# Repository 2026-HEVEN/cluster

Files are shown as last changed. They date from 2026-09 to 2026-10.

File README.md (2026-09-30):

# HEVEN Cluster 펌웨어

**2026 영광 대회 · 계기 클러스터(Instrument Cluster)** — ESP32가 CAN/BLE로 차량 상태(속도·전압·SOC·온도·에러)를 **받아서** LCD에 표현하고, 계기판 버튼 입력을 VCU로 보냅니다. PCB V3에서는 VESS PWM도 Cluster가 직접 출력합니다. VCU와 달리 **안전 임계가 약한 표시 전용 보드**입니다.

> 🤖 **AI 에이전트/팀원은 [`AGENTS.md`](AGENTS.md)를 먼저 읽으세요** — 무엇을 고쳐도 되고 무엇을 건드리면 안 되는지 규칙이 있습니다.

---

## 한눈에

- **스택**: PlatformIO + Arduino-ESP32, TWAI(CAN), ILI9341 LCD. 화면은 **패널 독립적 1bpp 프레임버퍼**(위젯이 그림) + `display_blit`(ILI9341로 blit)
- **구조**: 잠긴 코어(CAN·프레임버퍼·blit) + 팀원이 채우는 순수 모듈(`src/modules/`). VCU와 **동일한 2층 설계**지만 안전 FSM·50ms 라이프 태스크가 없고 CAN은 **수신(RX) 위주**입니다.
- **상태**: ESP32 빌드 성공, 호스트 native 테스트 111개 통과

## 사용자 문서

- [계기판 기능 및 한계](docs/ui_report/REPORT.md)
- [계기판 사용설명서](docs/ui_report/USER_MANUAL.md)
- [추가 CAN 정보 및 실차 확인 사항](docs/ui_report/CAN_DATA_REQUIRED.md)

## 빠른 시작

```bash
# 1. 이 레포를 깨끗한 위치에 클론
git clone https://github.com/2026-HEVEN/cluster.git
cd cluster

# 2. PlatformIO 설치 (한 번만) — VS Code면 PlatformIO IDE 확장 설치로 대체 가능
uv tool install platformio      # 또는: pipx install platformio

# 3. 노트북에서 테스트 (하드웨어 불필요)
pio test -e native

# 4. 보드에 빌드 & 업로드 (ESP32 연결 상태에서)
pio run -e esp32dev -t upload
```

> 🧪 **테스트가 처음이거나 Windows 사용자라면** → 노션 [펌웨어 테스트 실행 방법](https://www.notion.so/390913e532e68199a9b5e340b73e9e71) 참고. AI에 복붙할 프롬프트 + "이렇게 나오면 성공" 출력 예시 + Windows(WSL2/MinGW) 셋업까지 있습니다. (보드 업로드는 Windows도 그냥 되고, `native` 단위테스트만 host 컴파일러가 필요해요.)

> ℹ️ 모터컨트롤러 값은 MCU→VCU 피드백 프레임을 Cluster가 같은 CAN 버스에서 수신합니다. BMS SOC는 `LWS-1608` BLE BMS에 Cluster ESP32가 직접 연결해 표시용 telemetry로만 읽습니다.
> ℹ️ 계기판 속도 표시는 VCU가 내부 `vehicle_speed_compute()`로 산출한 단일 차량속도 프레임 `0x1803C0D0`을 사용합니다. 이 값은 전륜 기준 보정 로직을 거친 `km/h x 10` 값이며, Cluster는 다시 네 바퀴 평균을 내지 않습니다.
> ℹ️ GPS Lap Start는 현재 GNSS fix 위치를 출발점으로 저장합니다. 이후 VCU 단일 차량속도 `0.5 km/h` 초과가 `150ms` 이상 지속되면 랩타이머를 시작하고, 다시 출발점 반경 `2.0m` 안으로 들어오면 랩을 갱신합니다.

## 현재 하드웨어 핀맵 (PCB V3)

| 구분 | 기능 | ESP32 GPIO | 연결/동작 |
|---|---|---|---|
| CAN | TXD | GPIO13 | CAN 트랜시버 TXD |
| CAN | RXD | GPIO14 | CAN 트랜시버 RXD |
| LCD ILI9341 | CS / RST / DC | GPIO23 / 22 / 21 | LCD 제어 |
| LCD / Touch SPI | MOSI / SCK / MISO | GPIO17 / 18 / 35 | 공용 SPI |
| LCD Touch XPT2046 | T_CS | GPIO16 | Touch chip select |
| GPS ZED-F9P | RX / TX / PPS | GPIO25 / 26 / 27 | 115200 baud NMEA/UBX, RTCM3 및 PPS |
| VESS | PWM | GPIO4 | 반전 MOSFET 구동, 50Hz 고정. 외부 RX-TH에는 1~2ms High 펄스 출력 |
| HMI | TV | GPIO32 | 토글 스위치, PCB 외부 10k 풀업, ON=LOW |
| HMI | Paddock | GPIO33 | 토글 스위치, PCB 외부 10k 풀업, ON=LOW |
| HMI | HOME | GPIO19 | 순간 푸시 버튼, PCB 외부 10k 풀업, ON=LOW |
| HMI | GPS Lap | GPIO5 | 순간 푸시 버튼, PCB 외부 10k 풀업, ON=LOW |
| HMI | Regen bit0 / bit1 | GPIO36 / 39 | 로터리, ON=LOW, 두 핀 모두 외부 풀업 필요 |
| Sense | START_IN | GPIO34 | 시동 전원 감지 ADC. 버튼 출력 핀이 아님 |

GPS TX2는 PCB V3에서 Cluster ESP32 `GPIO25` RX에 연결한다.

Cluster는 부팅 시 ZED-F9P UART1/UART2가 460800 baud로 설정되어 있더라도 UBX 설정으로 115200 baud로 낮춘 뒤 통신한다. NMEA가 끊기면 115200 baud 복구를 다시 시도하므로, 같은 GPS TX에 연결된 외부 로거도 115200 baud로 유지할 수 있다.

RTK 사용 시 Cluster ESP32가 Wi-Fi로 NTRIP caster에 접속하고, 수신한 RTCM3 바이트를 가공 없이 `GPIO26` UART TX로 ZED-F9P RX2에 전달한다. 실제 Wi-Fi/NTRIP 계정정보는 `include/ntrip_secrets.h`에 넣고 Git에는 올리지 않는다. `include/ntrip_secrets.example.h`를 복사해서 사용한다.

Cluster는 ZED-F9P RMC의 Speed Over Ground를 km/h로 변환해 새 RMC마다 Extended CAN `0x18F9FFC0`으로 송신한다. 속도는 0.01 km/h/bit이며 같은 프레임에 RMC fresh, GPS fix, RTK FLOAT/FIXED, speed valid, GGA quality와 RMC age를 포함한다. 상세 byte layout은 `docs/CAN_PROTOCOL.md`를 따른다.

회생제동 입력은 GPIO36/39 두 비트 로터리다. 0단은 OFF, 1~3단은 모두 같은 ON 요청으로 인코딩한다. 실제 회생 가능 여부와 전류 제한은 VCU가 최종 판단한다.

GPIO15는 현재 펌웨어에서 사용하지 않는다. GPIO15는 strapping pin이므로 외부 회로가 부팅 순간 강하게 잡아당기지 않게 주의한다.

GPIO34는 PCB V3의 START_IN 전원 감지 ADC다. 5ms마다 분압된 핀 전압을 읽고, 1.5V 이상에서 ON, 1.0V 이하에서 OFF로 판정하며 20ms 디바운스를 적용한다. 이 값은 Car Check의 VCU/SENSOR 상세 화면에 표시할 뿐 차량 제어에는 사용하지 않는다. 기어는 VCU에서 읽는다.
## 어디서 작업하나

| 폴더 | 내용 | 편집? |
|---|---|---|
| `src/modules/` | 순수 계산 함수 `xxx_compute()` | ✅ **여기서만** |
| `test/` | 노트북 단위 테스트 | ✅ |
| `src/core/`, `src/logic/`, `include/` | CAN·framebuffer·display_blit·스케줄러·타입 | 🔒 잠김 |
| `platformio.ini`, `src/main.cpp` | 빌드 설정·진입점 | 🔒 잠김 |

새 모듈을 추가하거나 기존 `compute()`를 채우는 법 → [`docs/ADDING_A_MODULE.md`](docs/ADDING_A_MODULE.md)

## 모듈 목록 (FILL-IN)

- `hmi_input` — config 스위치(패독·TC·회생·디버그) → `ClusterCommand` (CAN으로 VCU에 전송)
- `widgets/` — 계기판 화면 위젯 (speed·battery·warnings·gear ...). 1bpp 프레임버퍼에 그림.
  새 위젯 추가법: `docs/ADDING_A_WIDGET.md`

> 표시는 패널 독립적 **1bpp 프레임버퍼**로. 실제 패널 blit(`display_blit`)은 하드웨어 확정 후 구현.

## 문서

| 문서 | 내용 |
|---|---|
| [`AGENTS.md`](AGENTS.md) / `CLAUDE.md` | 작업 규칙 (에이전트·팀원 필독) |
| [`docs/ADDING_A_MODULE.md`](docs/ADDING_A_MODULE.md) | 모듈 추가/작성 절차 |
| [`docs/CAN_PROTOCOL.md`](docs/CAN_PROTOCOL.md) | CAN 메시지 명세 (VCU/Cluster 공유 단일 출처) |

> 전체 설계 원리(compute/update 분리, state 격리, 테스트 등)는 **VCU 레포의 [`ARCHITECTURE.md`](https://github.com/2026-HEVEN/vcu/blob/main/docs/ARCHITECTURE.md)** 와 동일합니다.

## 아직 미구현 (의도된 TODO)

- **VCU 표시 상태 프레임 구현** — VCU가 `0x1801C0D0`으로 확정 기어/HV/브레이크 상태를 보내면 Cluster가 그 값을 우선 표시합니다.
- **BMS BLE 실차 검증** — `LWS-1608` BLE 이름, `FFE0/FFE1/FFE2` 특성, SOC/current 부호를 실제 배터리팩에서 확인해야 합니다.

## 버전 기록 (Changelog)

> 각 버전은 git 태그로도 관리됩니다 → [GitHub Releases](https://github.com/2026-HEVEN/cluster/releases)
> **새 버전 올릴 때:** 아래에 항목 추가 → `git tag vX.Y` → `git push origin vX.Y`.

### v1.1.1 (2026-07-06) — 위젯 레이아웃 렌더 테스트
- `test/test_render_layout`: `app_wiring.cpp`의 위젯 배치를 그대로 재현해 24bit BMP로 덤프하는 시각화 테스트 추가. `pio test -e native -f test_render_layout` 로 실행 → `render_layout.bmp` 생성(Windows 사진 앱/그림판 등 추가 도구 없이 바로 열림), 위젯별 할당 공간을 박스로 표시
- `.gitignore`에 `*.bmp` 추가

### v1.1 (2026-06-29) — 디스플레이 프레임버퍼 재설계
- 패널 독립적 **1bpp 프레임버퍼**(320×160) + 위젯 모듈(speed · battery · warnings · gear) 도입 — 렌더링을 모듈로 넘겨 자유도↑, host 테스트 가능(ASCII 시각화)
- `hmi_input` → **`ClusterCommand`**(paddock · TC · regen · debug) 의미 커맨드 패턴, **패독 모드** 추가
- **제거**: `vess`, `indicators`, `display_render`(U8g2), `io_expander`(MCP23017)
- `display_blit` stub(패널 확정 후 구현), CAN 커맨드 레이아웃(`CAN_PROTOCOL.md` §5.7) 갱신

### v1.0 (2026-06-29) — 초기 Cluster 펌웨어 베이스
- 잠긴 코어(CAN RX · MCP23017 · U8g2 OLED) + 순수 모듈(display · indicators · vess · hmi_input)
- PlatformIO native 테스트, AGENTS/ADDING_A_MODULE/CAN_PROTOCOL 문서

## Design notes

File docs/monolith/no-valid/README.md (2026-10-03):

# Configurations without standalone validity decoders

- RaceMonitor: 317 channels, SOC included.
- Full: 430 channels, SOC included.

Standalone channel names containing the word `Valid` are removed. Existing
value decoders, including their validity filters, remain unchanged to avoid
displaying invalid sentinel temperatures or LV voltages as physical values.
BLE connection status and other non-validity diagnostics remain available.
Removing a decoder does not remove any CAN frames or reduce bus traffic.

Lap history now keeps the active lap at 5 Hz, the nine latest completed laps
at 1 Hz each, and older completed laps at 0.1 Hz each. These are target rates,
not guaranteed delivery during bus faults or saturation. Old lap values may
show missing in Control Hub if its display timeout is shorter than ten seconds.
The CAN IDs and byte layout are unchanged; the JSON needs no rate setting.

Generation: `tools/remove_monolith_valid.py`. Originals are preserved and all
settings except the explicitly removed channels are checked for equality.

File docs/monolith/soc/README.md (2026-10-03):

# BMS SOC decoder configurations

These copies preserve the supplied RaceMonitor and Full configurations and add
or normalize these channels:

| Name | Extended CAN ID | Range | Type | Multiplier | Unit |
| --- | --- | --- | --- | --- | --- |
| BMS SOC | 0x18F3FFC0 | Byte 1 | unsigned byte | 1 | % |
| BMS Data Valid | 0x18F3FFC0 | Bit 0 | unsigned bit | 1 | State |
| BMS BLE Connected | 0x18F3FFC0 | Bit 1 | unsigned bit | 1 | State |

Offsets are zero. SOC uses little endian and no payload filter, so every BMS
status frame updates its display. Treat SOC as usable only while Data Valid is
1; the decoder does not itself hide stale or disconnected values. BLE Connected
alone is not a freshness guarantee.

Cluster already schedules `bms_can_tx_update` every 100 ms (10 Hz), with both
status and detail sent by `send_bms_status`. This change does not modify that
schedule or the BLE polling rate. Repeated telemetry is not a new BMS measurement.
Successful delivery still depends on CAN health, BMS freshness, and Monolith's
own receive/render behavior. JSON import and on-device rendering need bench
verification; this configuration cannot guarantee an absence of missing values.

The RaceMonitor copy has 319 channels; Full has 436. Full already contained
BMS SOC, so it is not duplicated. Other decoders, units, and settings are retained.

Generation and validation: `tools/add_monolith_soc.py`. Validation covers
unrelated-setting preservation, SOC values 0/1/78/100, validity flag combinations,
idempotence, and a JSON round trip.

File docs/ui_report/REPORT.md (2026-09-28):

# HEVEN Cluster 계기판 기능 및 한계

작업 기준일: 2026-09-28. 대상: PCB V3 Cluster ESP32 / 320×240 ILI9341 LCD.

이번 작업은 노트북 없이 차량 상태를 확인하도록 Car Check를 구성하고, 연결 이력과 최근 60초 그래프를 추가한 펌웨어 변경이다. 그래프를 열 수 있는 항목에는 `*`를 표시했다. 본 문서의 이미지는 **실제 펌웨어 화면 그리기 코드에 예시 데이터를 넣어 생성한 화면 미리보기**이며, 실차 측정 사진이나 실차 검증 결과는 아니다.

운전자 조작 순서는 [Cluster 계기판 사용설명서](USER_MANUAL.md)에 별도로 정리했다.

## 1. 무엇이 바뀌었나

| 항목 | 이전 로컬 구현 | 이번 변경 |
| --- | --- | --- |
| 기본 화면 | WSS 속도, 기어, HV SOC, HV/LV 전압, 랩 정보와 하단 Car Check 진입 칸 | WSS 속도 확대. 기어·HV SOC·HV/LV 전압을 오른쪽 정렬하고 스로틀·전력 막대와 랩 정보를 남는 공간에 재배치 |
| 브레이크 | 압력 데이터가 없어 빈 `BRK --` 막대 표시 | 압력 막대 삭제. VCU의 유효한 Brake Active가 ON일 때만 기어 왼쪽에 `BRK` 표시 |
| 전력 표시 | POWER/CHARGE를 같은 방향의 막대로 표시 | 중앙 0 기준 양방향 막대. CHARGE는 왼쪽, POWER는 오른쪽으로 채워 방향을 즉시 구분 |
| GPS LAP 정지/재개 | Warning 상태에 따라 버튼 동작이 달라져 랩 시작이 제한됨 | Warning 여부와 무관하게 단일 클릭으로 START·STOP·RESUME. 기존 기준점·결승선·랩 기록을 유지하고 정지 시간은 랩타임에서 제외 |
| Car Check | 모터·전원·VCU·GPS 구분 | 최신 VCU 센서와 제어 적용 상태, 차단 이유를 세부 화면에 연결 |
| 그래프 접근 | 홈 화면 WSS 숫자 | 속도 숫자는 WSS 그래프, 전력 막대는 POWER 그래프로 연결. 나머지 홈 영역은 Warning 또는 Car Check로 연결하고 세부 화면의 `*` 항목도 그래프 제공 |
| 저장량 | WSS 최대 20 Hz·10분, 가용 heap에 따라 최대 96 KB | 선택한 12개 수치 2 Hz·최근 60초, 고정 크기 RAM |
| 좌우 비교 | 개별 수치 확인 | 버스 전류·상 전류·버스 전압을 같은 그래프에 표시. L 점선 / R 실선 |
| 통신 진단 | 현재 LIVE/WAIT 확인 | 연속 연결 시간, 단절 횟수, 모터 고장 발생/해제 이력 |
| 화면 갱신 설정 | 약 15 Hz | 50 ms / 20 Hz 목표 |
| LV SOC | 공급 데이터 없음 | 막대와 %를 만들지 않고 LV 전압만 표시 |
| 상세 화면 행 | 화면별 구분 방식이 달랐음 | 모터·전원·VCU·센서·GPS 화면의 데이터 행 구분선을 제거해 통일 |
| PCB 핀맵 | 기존 PCB GPIO 배치 | PCB V3의 LCD·Touch·CAN·GNSS·스위치 핀으로 변경하고 외부 10 kΩ 풀업 기준 입력으로 통일 |
| START 입력 | 표시 없음 | GPIO34 ADC로 분압된 START_IN을 감시하고 VCU/SENSOR 화면에 ON/OFF와 ADC 전압 표시 |
| VESS 출력 | 비반전 GPIO 출력 전제 | GPIO4 단일 반전 MOSFET 회로에 맞춰 PWM duty를 보상하고 외부 출력 2 ms HIGH pulse 유지 |
| 구동계 이상 감지 | 컨트롤러 fault bit와 통신 단절만 경고 | 반복 RPM 결손과 좌우 RPM 발산을 별도로 감지하고 운전자 경고·이력에 기록 |

CAN bitrate는 250 kbps이며 기존 BMS/GNSS/Lap 송신 주기는 유지한다. 화면 갱신 설정을 올렸다고 원천 센서의 측정률이 올라가는 것은 아니다. 실제 LCD 갱신률과 BLE·Wi-Fi 동시 동작 부하는 실물에서 확인해야 한다.

## 2. 화면 이동

기본 화면에서 **큰 속도 숫자 영역을 누르면 WSS 그래프**, **중앙 양방향 전력 막대를 누르면 POWER 그래프**가 열린다. 두 영역을 제외한 나머지 화면을 누르면 경고가 있을 때 Warning 이유 화면으로, 경고가 없을 때 Car Check로 이동한다. 별도의 작은 `CAR CHECK` 버튼을 찾을 필요가 없도록 홈 화면 대부분을 진입 영역으로 사용한다. Car Check의 네 영역은 모터, 전원, VCU·센서, GPS·RTK이다.

세부 화면에서 `*`가 붙은 항목을 누르면 해당 그래프가 열린다. 오른쪽 위 `BACK`은 그래프를 열었던 화면으로 돌아간다. PCB V3 GPIO19 순간버튼은 어느 화면에서나 기본 화면으로 돌아가는 HOME 기능을 유지한다. 화면 하단 `LINKS / HISTORY`에서 연결 상태와 이벤트 이력을 확인한다.

| 화면 | `*`로 표시한 그래프 항목 |
| --- | --- |
| 모터 상세 | BUS V, BUS A, PHASE A. L/R 같은 그래프 |
| 전원 | BMS VOLTAGE, EM HV VOLTAGE, EM LV VOLTAGE, EM HV CURRENT |
| VCU | THROTTLE, WSS REPRESENTATIVE |
| GPS | FIX / RTK |

홈 화면에서는 WSS 숫자와 전력 막대를 그래프로 연결한다. 홈 POWER 그래프는 전력 절댓값을 표시하고 POWER 구간은 실선, CHARGE 구간은 점선으로 구분한다. 스로틀 그래프는 VCU 세부 화면의 `THROTTLE *`에서 연다. 조향·IMU·온도·RPM은 이번에 이력 저장 대상으로 추가하지 않았으므로 별표가 없다.

GPS LAP 버튼의 단일 클릭은 더블클릭 판별을 위해 약 320 ms 뒤 처리한다. Warning 여부와 관계없이 랩 세션이 없으면 유효한 GPS Fix 위치를 Start/Finish로 설정하고 `LAP START SET`과 현재 랩 `L1`을 표시한다. 진행 중이거나 출발 대기 중이면 `LAP STOPPED`, 정지 상태에서 다시 누르면 `LAP RESUMED`를 표시한다. Resume 시 기존 기준점, 가상 결승선, 완료 랩과 현재 랩 경과시간을 유지하며 정지해 있던 시간은 제외한다. 첫 결승선 통과로 Lap 1을 기록하면 표시가 `L2`로 넘어간다. 320 ms 이내 빠른 더블클릭은 기존과 같이 `GPS LAP RESET`을 표시하고 기준점·결승선·모든 랩 기록을 초기화한다.

## 3. 각 화면 미리보기

### 기본 화면

구분선과 하단 Car Check 칸을 없애고 WSS 속도를 3자리 기준 14배 글꼴로 확대했다. 기어, `HV SOC`, 게이지, %, HV/LV 전압은 화면 오른쪽 끝을 동일 기준으로 정렬했다. 브레이크 압력 게이지를 제거하고 스로틀·전력 막대를 넓고 굵게 배치했으며 랩 정보를 위로 당겨 빈 공간을 줄였다. 스로틀은 VCU가 보낸 유효한 %를 사용한다.

차량 기어는 `N/R/D`만 표시한다. VCU 상태 프레임이 최근 300 ms 이내이고 Brake Active bit가 ON일 때만 기어 왼쪽에 `BRK`가 나타난다. 브레이크를 놓거나 VCU 상태가 오래되면 `BRK`를 지우므로 과거 상태를 계속 표시하지 않는다. `BRK`는 브레이크 압력이나 제동력의 크기가 아닌 **ON/OFF 상태**이다.

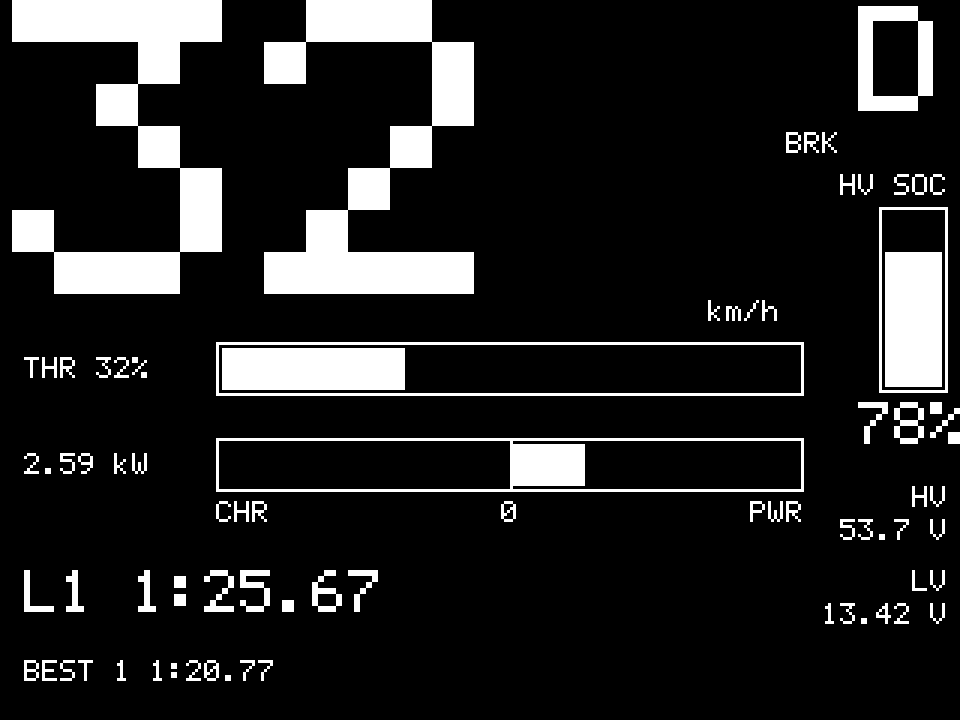
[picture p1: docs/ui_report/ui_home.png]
기본 화면


전력은 동일한 EM RECORD의 HV 전압과 전류로 `|V×I|/1000`을 계산하여 kW로 표시한다. 숫자는 막대 왼쪽에 두고, 스로틀 막대와 같은 시작점과 폭으로 정렬했다. 막대 아래에는 왼쪽부터 `CHR / 0 / PWR`을 배치한다. 중앙 `0`을 기준으로 **회생 충전(CHARGE)은 왼쪽**, **구동 전력 소비(POWER)는 오른쪽**으로 채워진다. 각 방향은 10 kW를 가득 찬 상태로 표시하며, 10 kW를 넘어도 숫자는 실제 계산값을 계속 표시한다. 현재 임시 방향 규칙은 **EM 전류가 0 이상이면 POWER, 0 미만이면 CHARGE**이다. 실차에서 알려진 구동·회생 조건과 비교해 부호가 반대라면 이 매핑만 뒤집으면 된다. 이는 규정 충족 여부를 판정하는 기능은 아니다.

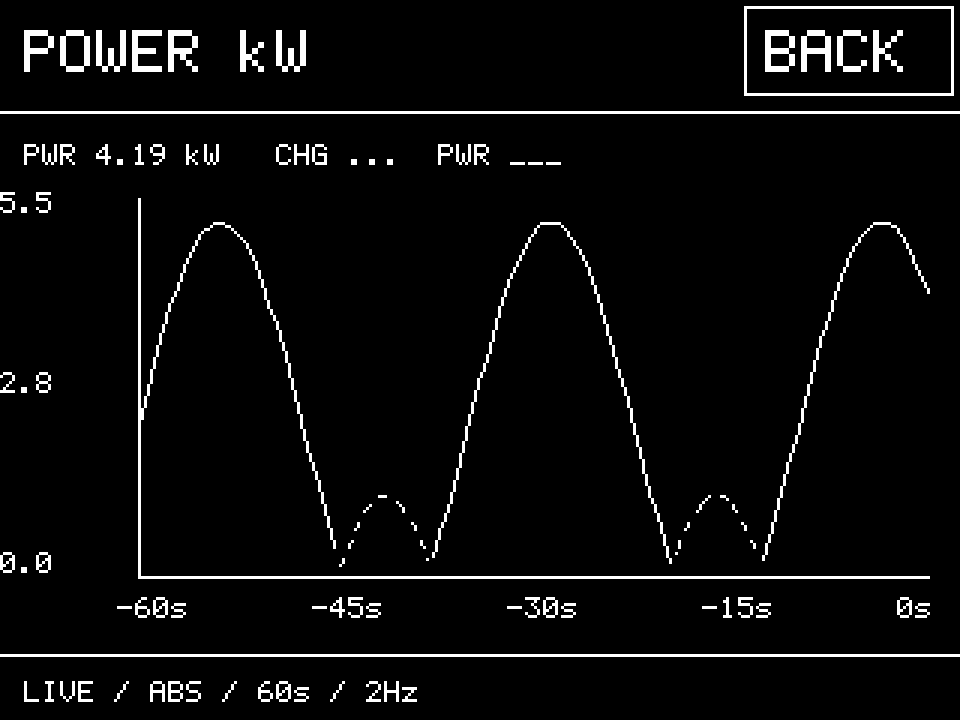
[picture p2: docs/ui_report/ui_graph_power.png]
홈 전력 이력 그래프


### Car Check 메뉴

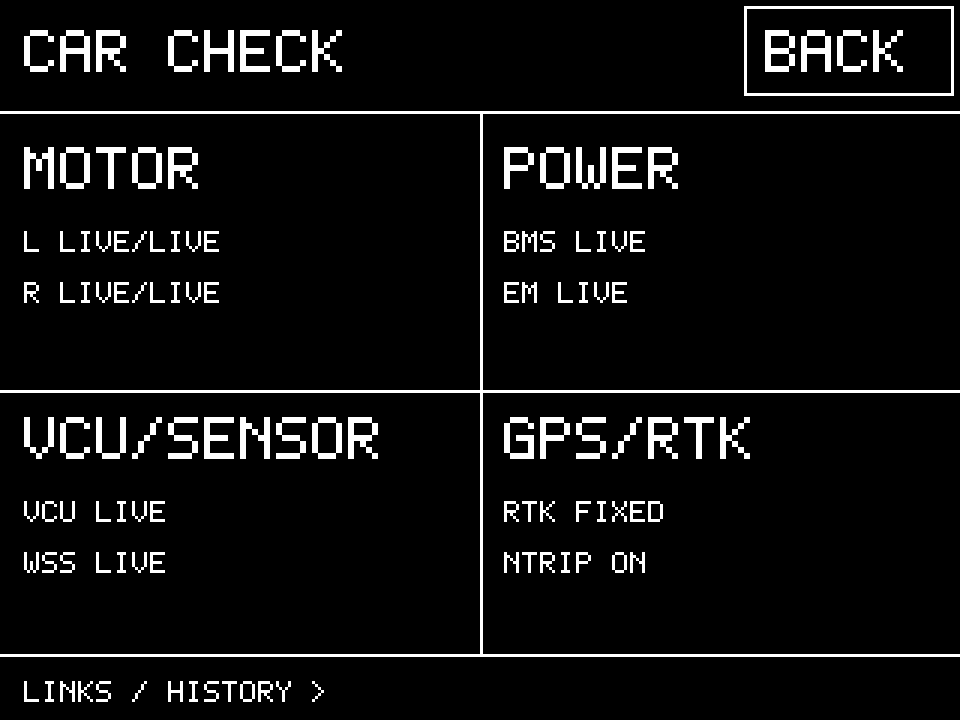
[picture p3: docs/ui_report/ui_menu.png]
네 영역 메뉴


모터 상세와 다른 상세 화면의 시각 구조를 통일하기 위해 데이터 행 사이의 가로 구분선을 제거했다. 제목 아래 기준선, `BACK` 버튼 외곽과 하단 `LINKS / HISTORY` 경계는 탐색 구조를 구분하기 위해 유지한다.

### 모터 상세

좌우 전압, 버스/상 전류, RPM, 모터/컨트롤러 온도, 상태와 고장 코드를 비교한다. 피드백 Part I과 II의 수신 유효성을 따로 검사하여 한 프레임이 들어왔다고 다른 프레임의 값까지 정상으로 표시하지 않는다.

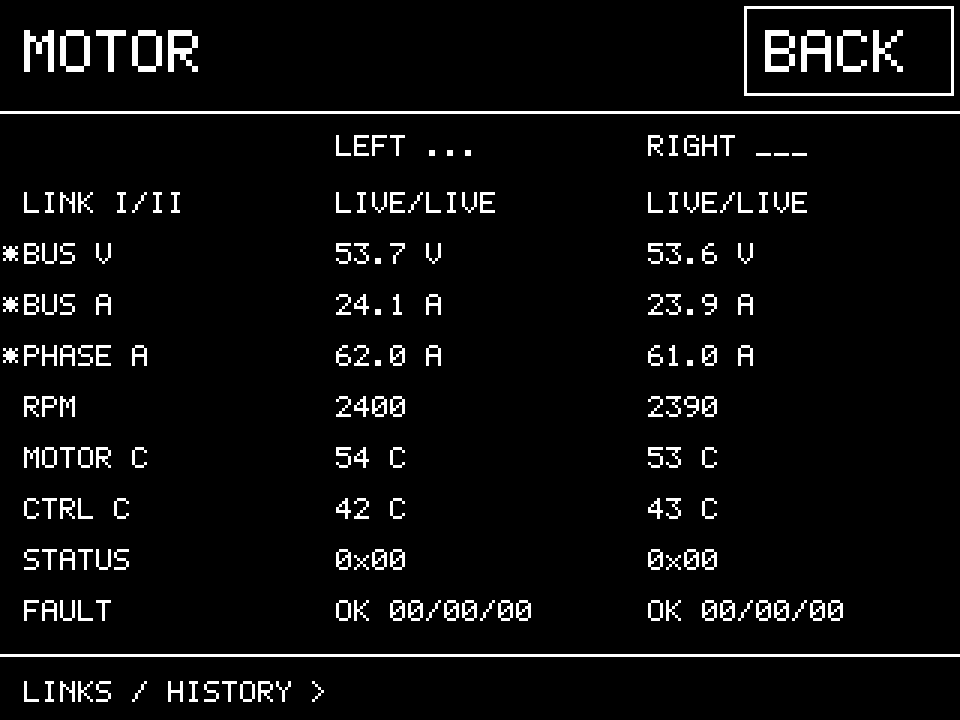
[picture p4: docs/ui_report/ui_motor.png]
모터 상세와 별표


미연결 컨트롤러는 `-- WAIT`로 표시한다. 저장되어 있던 0을 정상값으로 취급하지 않는다.

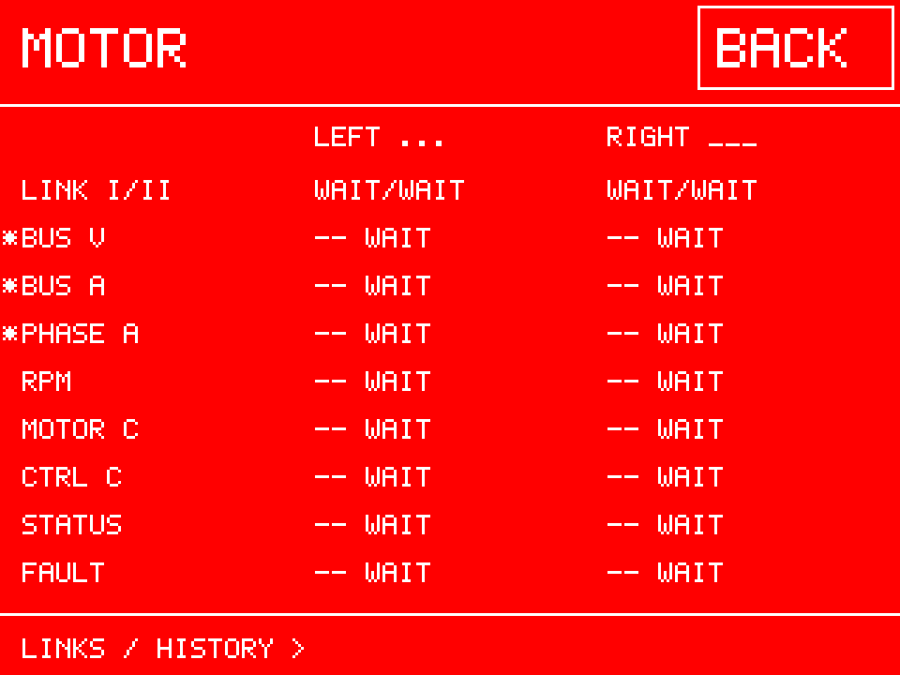
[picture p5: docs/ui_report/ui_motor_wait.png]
모터 미연결 화면


### 전원 상세

BMS SOC·전압·전류·온도·잔여 용량·SOH·사이클과 EM HV/LV 전압·HV 전류·CPU 온도를 표시한다. BMS 정보와 에너지미터 정보를 출처별로 구분한다.

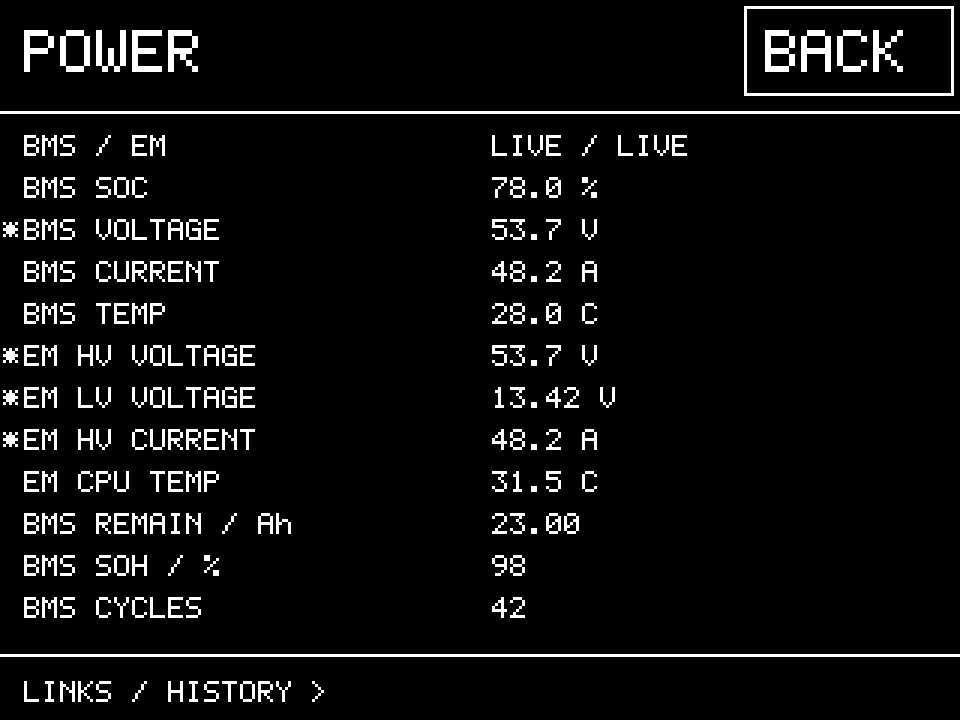
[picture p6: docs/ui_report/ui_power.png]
전원 상세


### VCU / 센서

기어, 디지털 브레이크 ON/OFF, HV 활성, 스로틀, WSS 대표속도와 요청/적용 상태를 확인한다. `>` 항목에서 센서 또는 제어 상세로 이동한다. 차량에 P 기어가 없으므로 홈 화면의 기어 표시는 N/R/D로 제한한다.

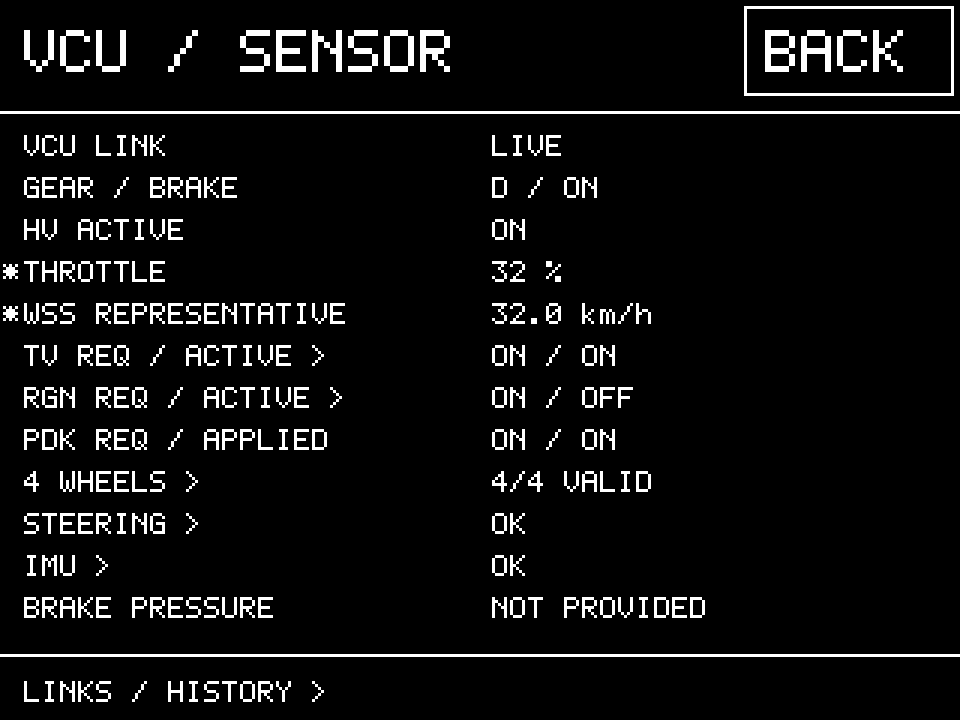
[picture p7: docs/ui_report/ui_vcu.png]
VCU 화면


### 개별 센서 상세

FL·FR·RL·RR 속도, 정규화 조향값, yaw rate, X/Y 가속도를 표시한다. 전송은 되었지만 valid가 꺼진 값은 `INVALID`, 유효성 정의가 없는 구버전은 `UNKNOWN`, 오래된 값은 `STALE`로 표시한다. 조향은 도(deg)가 아니며, IMU 축은 차량 장착 방향 검증이 필요하다.

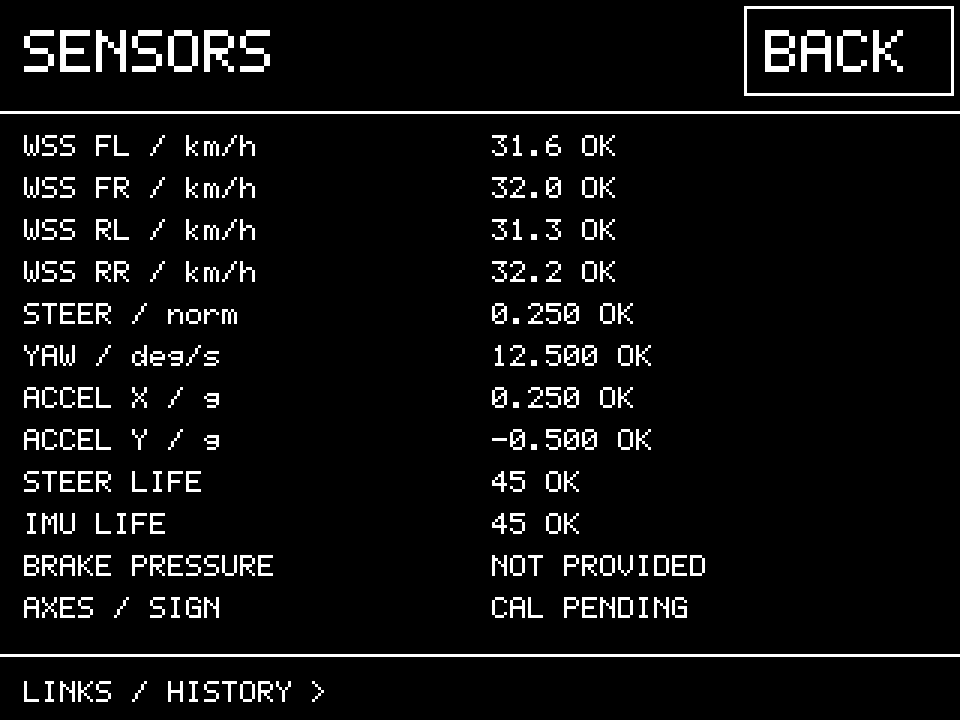
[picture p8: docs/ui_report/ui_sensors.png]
센서 상세


### 제어 요청과 적용 상태

Cluster의 스위치 요청과 VCU가 수신한 요청, VCU가 보고한 적용 상태를 구분한다. Regen Active가 ON이라고 실제 배터리에 충전 전력이 들어왔다는 뜻은 아니다.

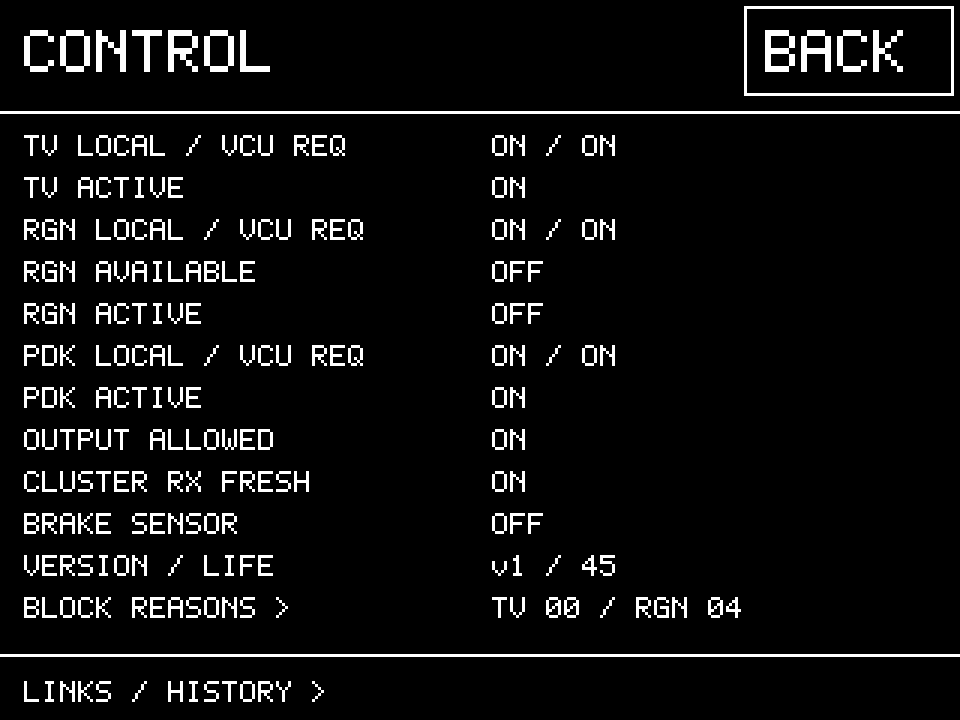
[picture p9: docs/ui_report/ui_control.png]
제어 상세


차단 이유는 TV와 회생제동의 각 조건을 YES/NO로 보여준다. 아래의 예시에서는 브레이크 센서가 없다는 회생제동 차단 조건을 확인할 수 있다.

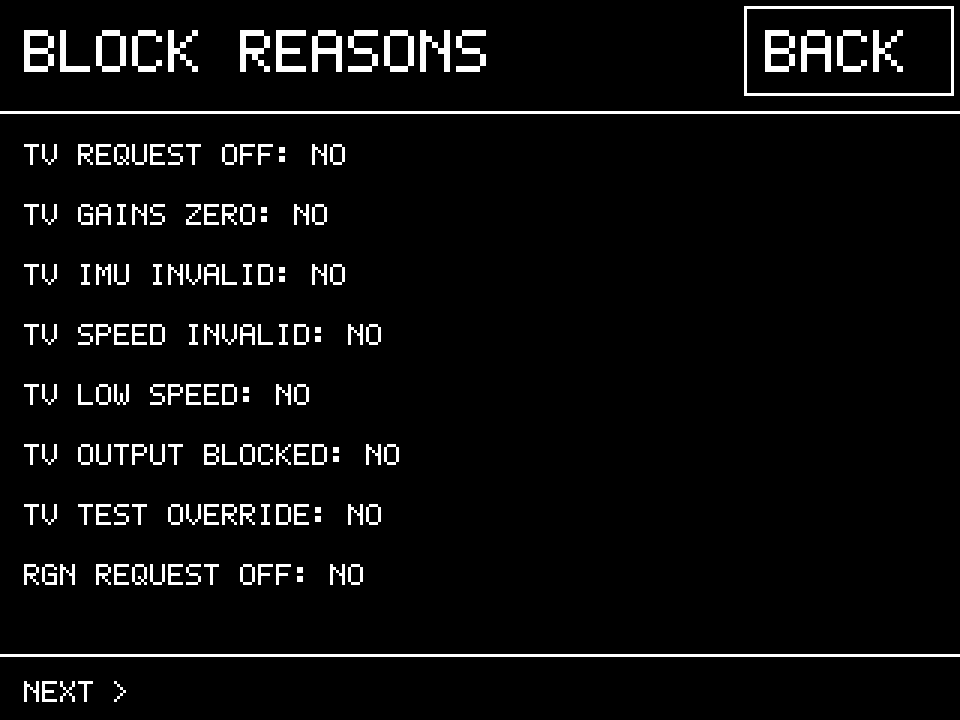
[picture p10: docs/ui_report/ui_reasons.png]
차단 이유 첫 페이지


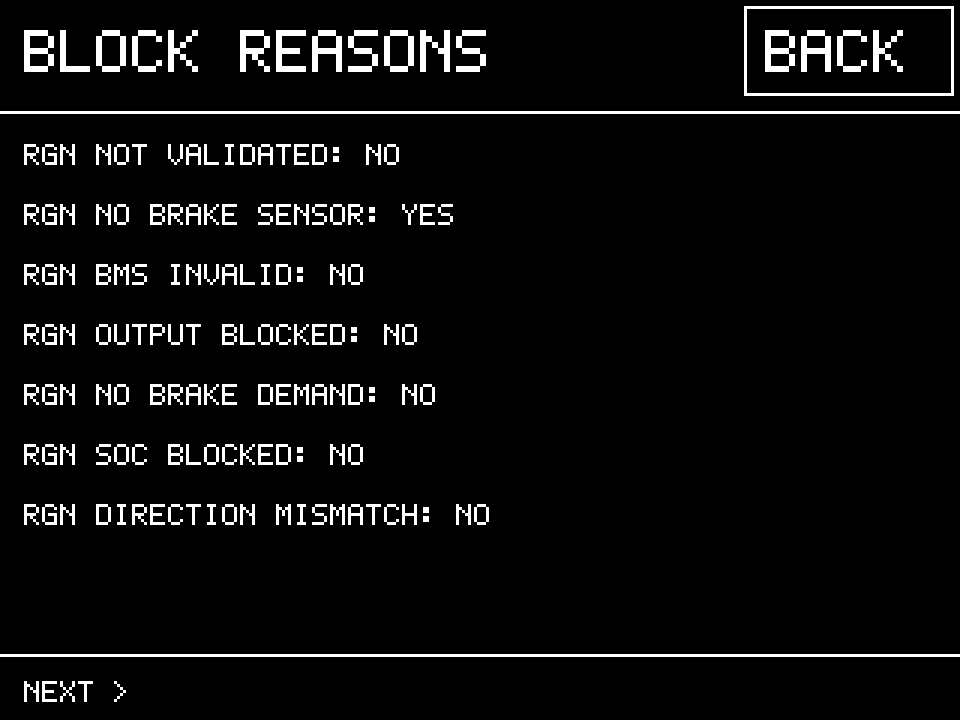
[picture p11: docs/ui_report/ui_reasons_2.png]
차단 이유 두 번째 페이지


### GPS / RTK

Fix/RTK, 위경도, 위성 수, HDOP, Wi-Fi, NTRIP, RTCM 수신 경과시간, 랩 상태와 PPS를 확인한다. NTRIP 연결과 RTCM 데이터 수신은 각각 별도로 판단한다.

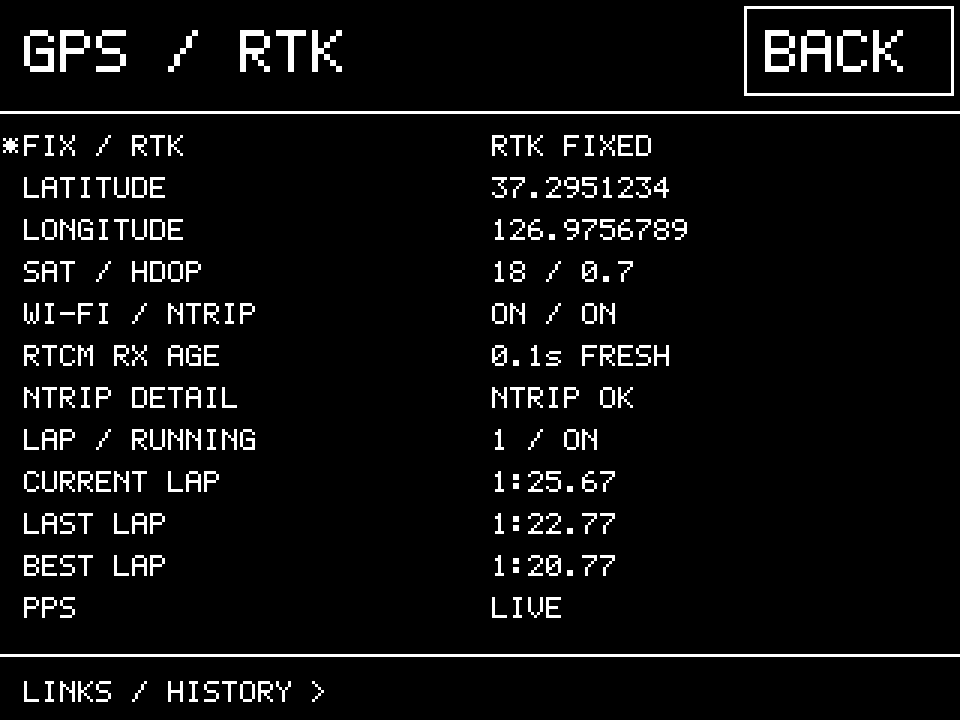
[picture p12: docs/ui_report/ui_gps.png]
GPS 상세


### 연결 업타임과 발생 이력

LIVE 옆 시간은 **현재 연결이 연속으로 유지된 시간**이다. 연결이 복구되면 다시 0부터 센다. `D`는 연결 단절 횟수, `F`는 새로 켜진 모터 고장 비트의 누적 횟수이다. 아직 한 번도 연결되지 않은 항목은 WAIT이며, 부팅 직후 미연결 상태를 반복 단절로 세지 않는다.

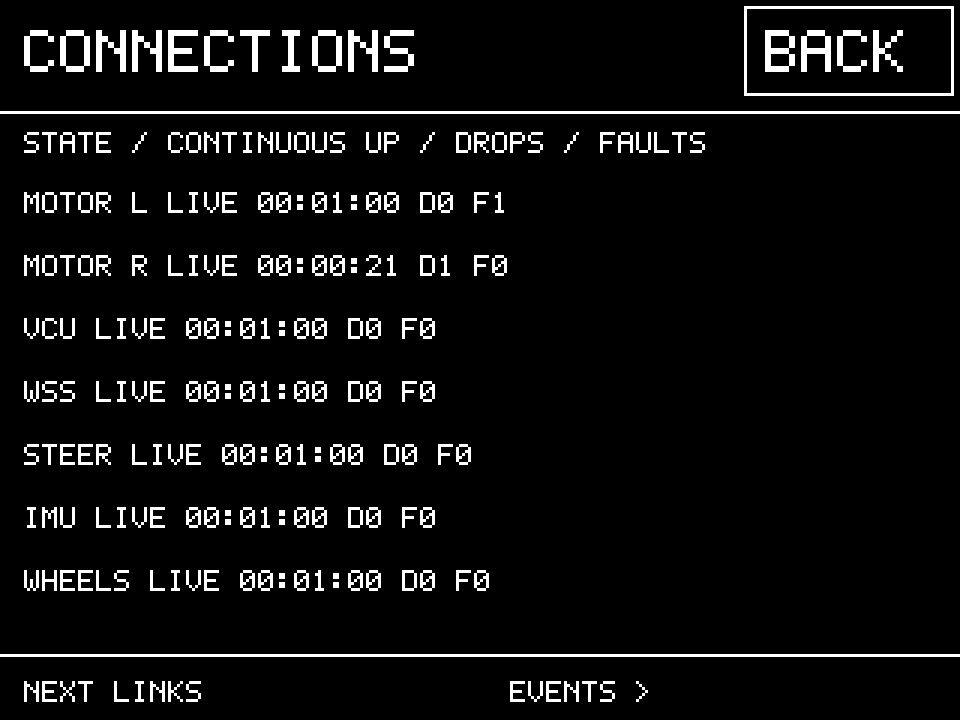
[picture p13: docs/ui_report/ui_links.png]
연결 상태 첫 페이지


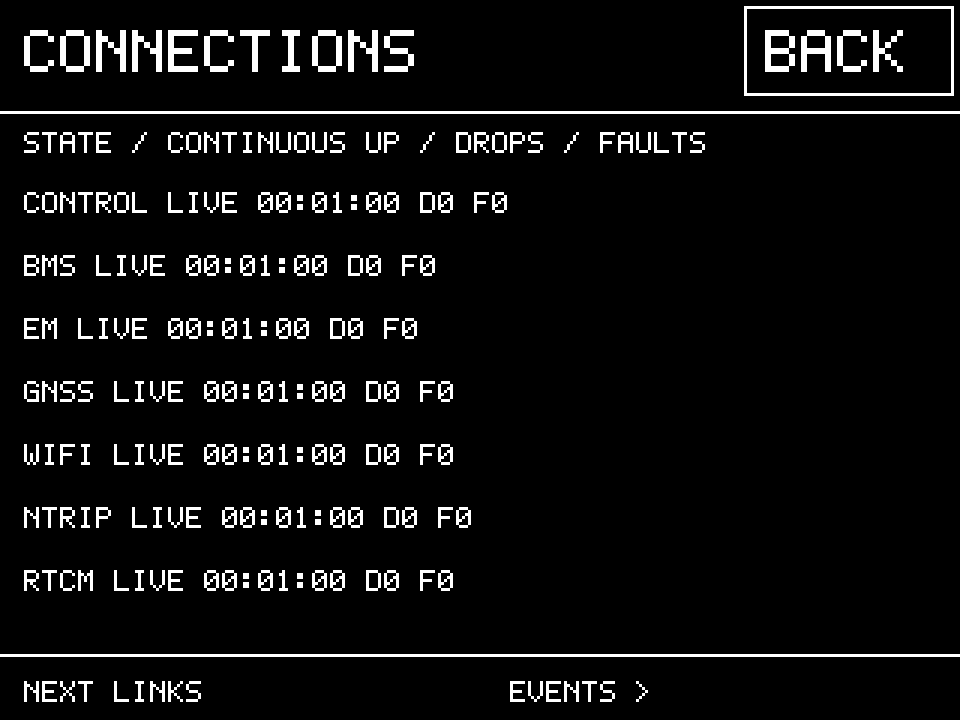
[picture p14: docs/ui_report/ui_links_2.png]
연결 상태 두 번째 페이지


최근 32개 이벤트를 RAM에 보관한다. 최초 연결, 단절, 복구, 모터 고장 발생과 해제를 시각과 함께 표시한다. 시각은 전원 투입 이후 경과시간이다. 저장 한도를 넘으면 가장 오래된 이벤트를 덮어쓰고 `overwritten` 수를 표시한다. 전원을 끄면 초기화되며 상용 ECU의 영구 고장 코드 저장을 대체하지 않는다.

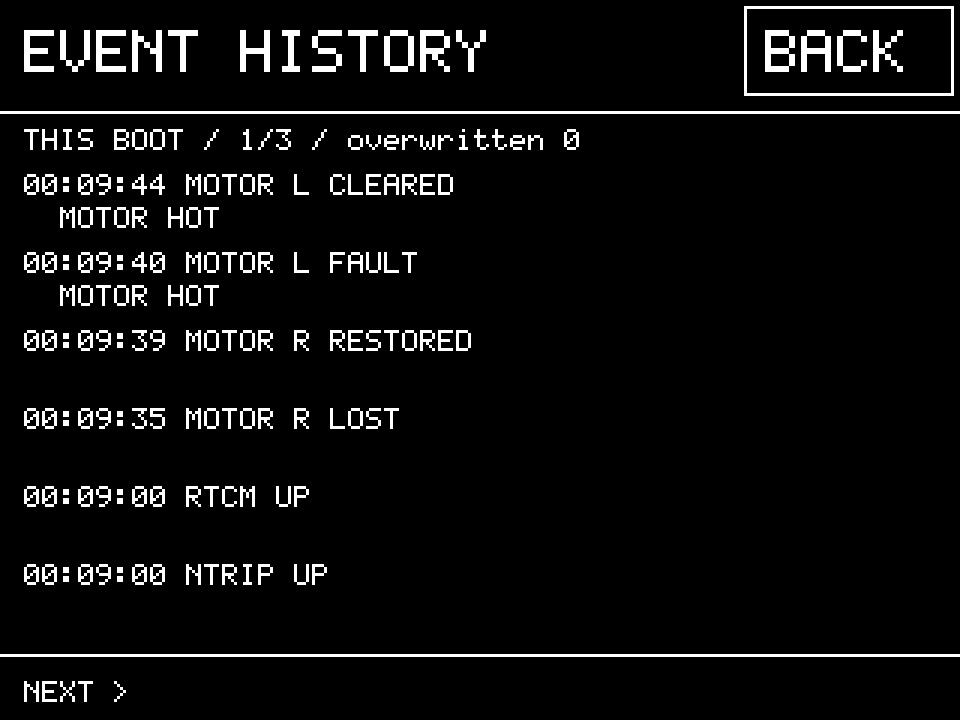
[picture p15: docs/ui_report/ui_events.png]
발생 이력


고장 프레임을 받지 못하는 동안에는 고장이 해제되었다고 기록하지 않는다. 다음 유효한 프레임이 들어온 뒤 해제 여부를 판정한다. 단절과 고장은 별개이므로 D/F도 별도로 센다. F는 현재 모터 고장 비트를 대상으로 하며, 다른 장치의 모든 고장까지 수집하는 기능은 아니다.

### Warning 이유

기존 경고 조건과 붉은 배경 표시 정책을 유지하며 경고 이유를 확인할 수 있다.

기존 모터컨트롤러 FB1의 좌우 RPM을 이용해 두 가지 이상 징후를 추가로 감시한다. `DRIVE RPM WARNING`은 `|RPM| ≤ 5`인 편측 결손이 회복 프레임으로 확인되고 2초 안에 3회 누적될 때 발생한다. `DRIVE SYSTEM FAULT`는 큰 쪽 RPM이 800을 넘고 작은 쪽의 3배를 초과하는 상태가 200 ms 이상 지속될 때 발생한다. 두 조건 모두 최신 좌우 CAN 데이터만 사용하며 CAN 단절 자체를 구동계 고장으로 오인하지 않는다.

경고는 5초간 우선 표시하고 진단 상태와 이벤트 이력은 재부팅 전까지 유지한다. 이는 특정 등속 조인트 파손을 확정하거나 토크를 차단하는 기능이 아니라 운전자에게 구동계 또는 RPM 피드백 이상 가능성을 알리는 기능이다.

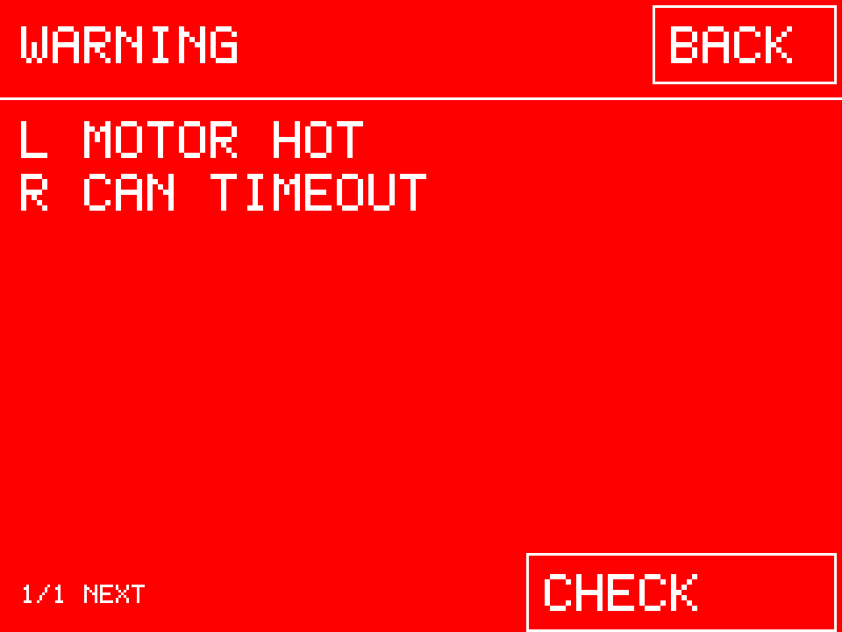
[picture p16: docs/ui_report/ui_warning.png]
Warning 화면


## 4. 최근 60초 그래프

숫자 이력은 500 ms마다 한 번 저장한다. 화면을 열지 않아도 기록하며, 열린 동안에도 계속 최신화한다. 저장 범위를 최근 60초로 제한했으므로 60초보다 오래된 기록을 스크롤해 조회하는 기능은 이번 버전에 없다. 장시간 분석은 TMA-1 로그를 사용한다.

상단 NOW 또는 L/R 숫자는 최신 상태를 사용한다. 2 Hz 그래프는 추세 확인용이며 짧은 전류 피크나 빠른 제어 응답을 검증하는 계측 로그가 아니다. 유효하지 않은 구간은 선을 끊고, 연결이 끊긴 값을 0으로 보간하지 않는다.

좌우 비교는 동일한 시간축·단위를 사용한다. L은 점선, R은 실선이다. 두 값이 일치하면 선이 겹칠 수 있으며, 임의로 위치를 어긋나게 표시하지 않는다. 상단 숫자로도 좌우 값을 비교할 수 있다. 전압 그래프는 작은 변화를 보기 위해 관측 전압 주변으로 세로축을 확대하므로, 왼쪽 축의 실제 범위를 함께 읽는다.

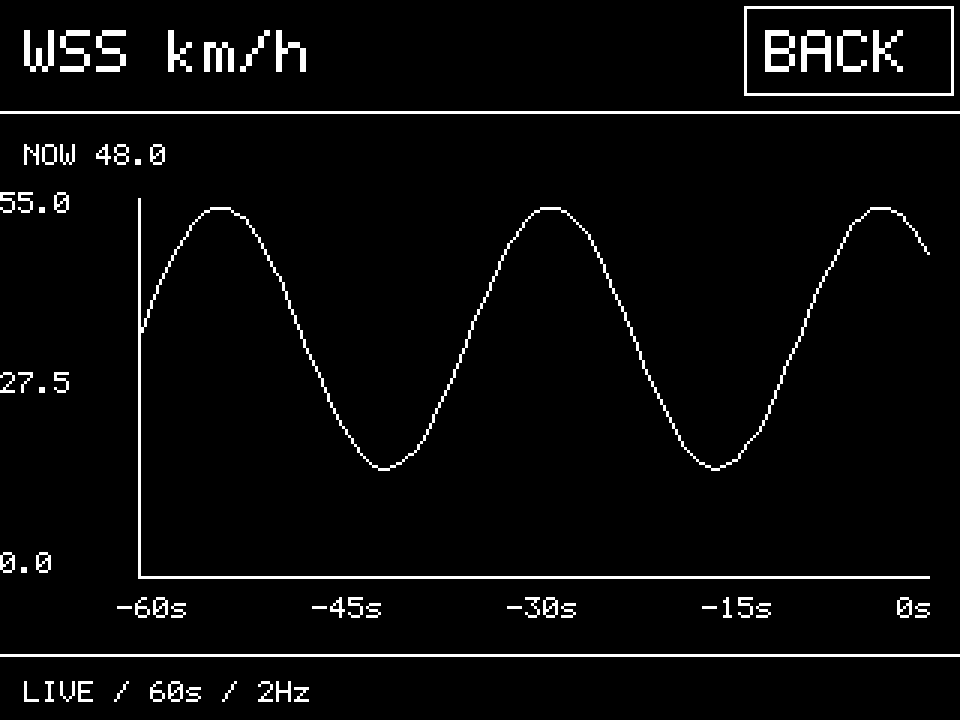
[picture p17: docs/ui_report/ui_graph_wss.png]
WSS 속도 그래프


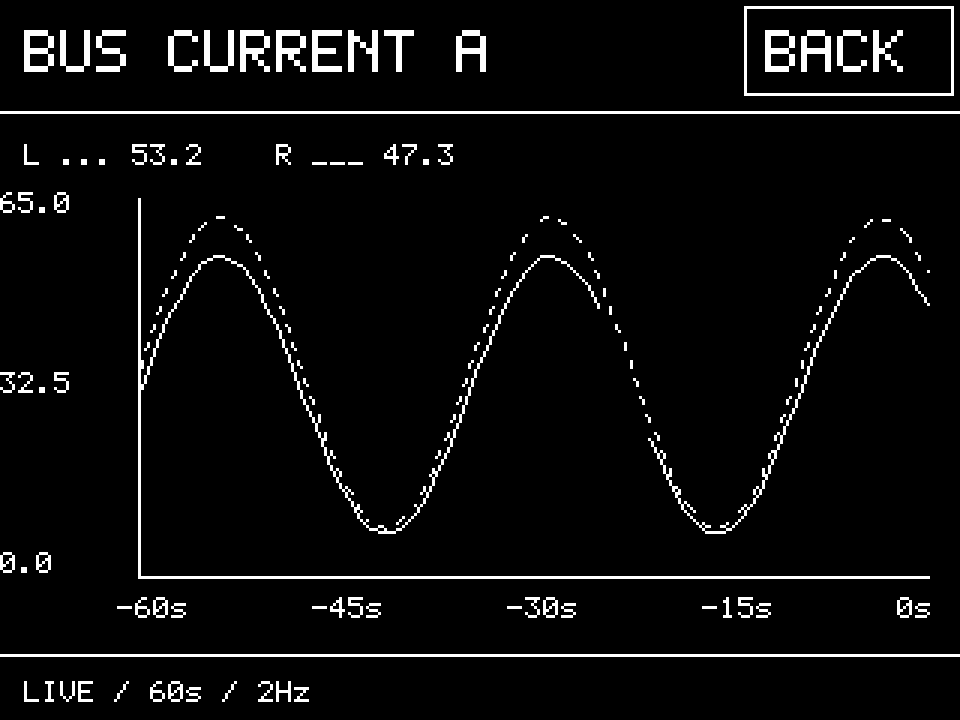
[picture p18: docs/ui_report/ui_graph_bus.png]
좌우 버스 전류 그래프


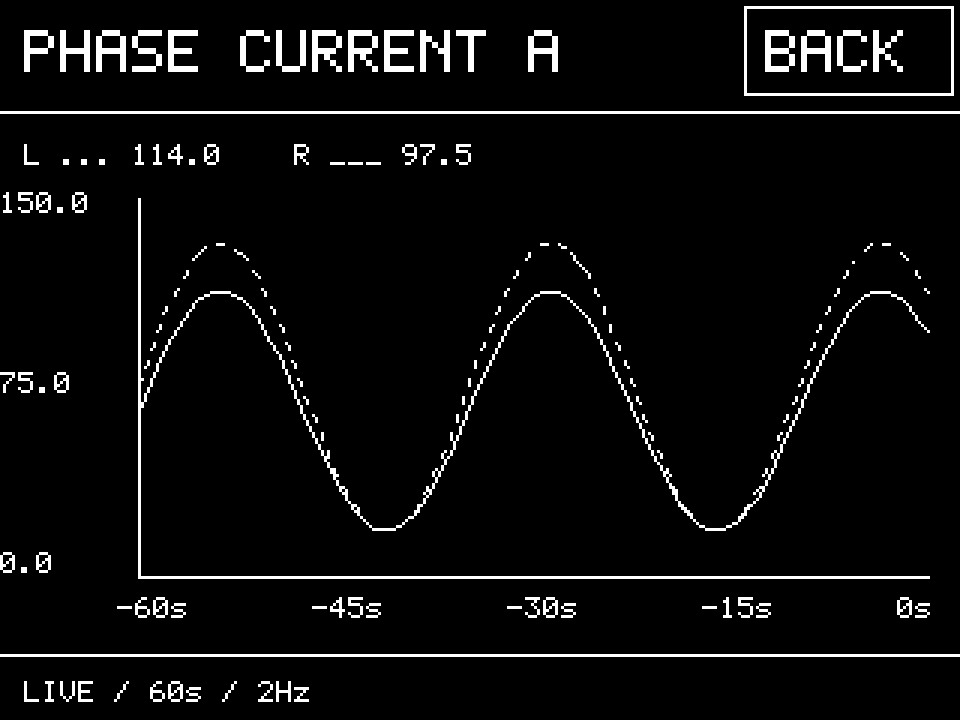
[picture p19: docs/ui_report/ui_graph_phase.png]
좌우 상 전류 그래프


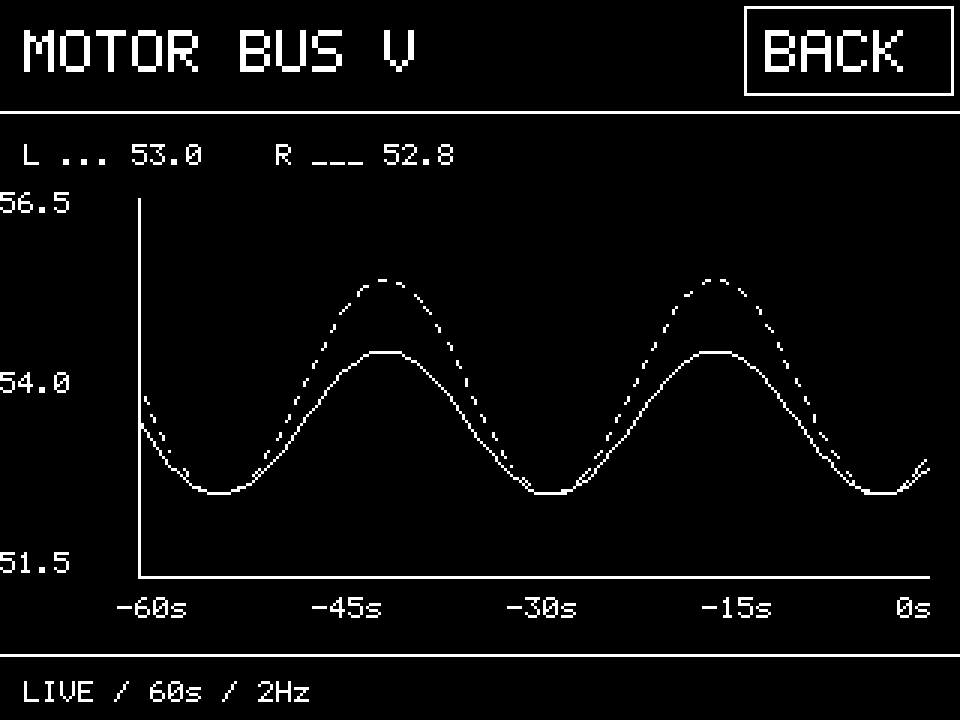
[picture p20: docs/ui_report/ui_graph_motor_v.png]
좌우 버스 전압 그래프


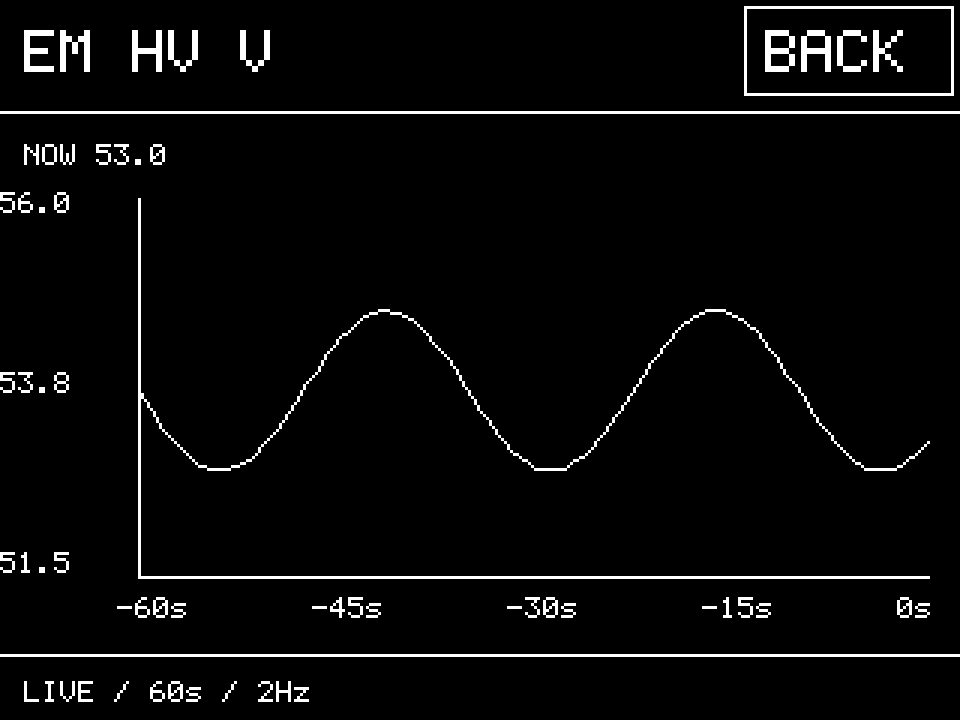
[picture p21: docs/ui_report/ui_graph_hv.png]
EM HV 전압 그래프


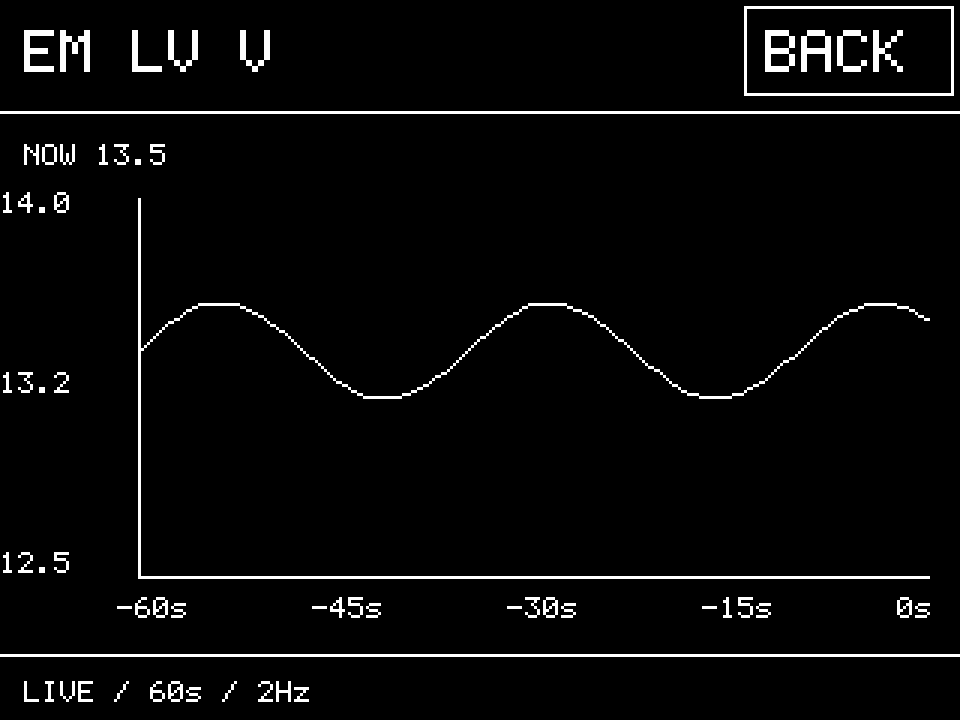
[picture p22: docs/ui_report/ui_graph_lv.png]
EM LV 전압 그래프


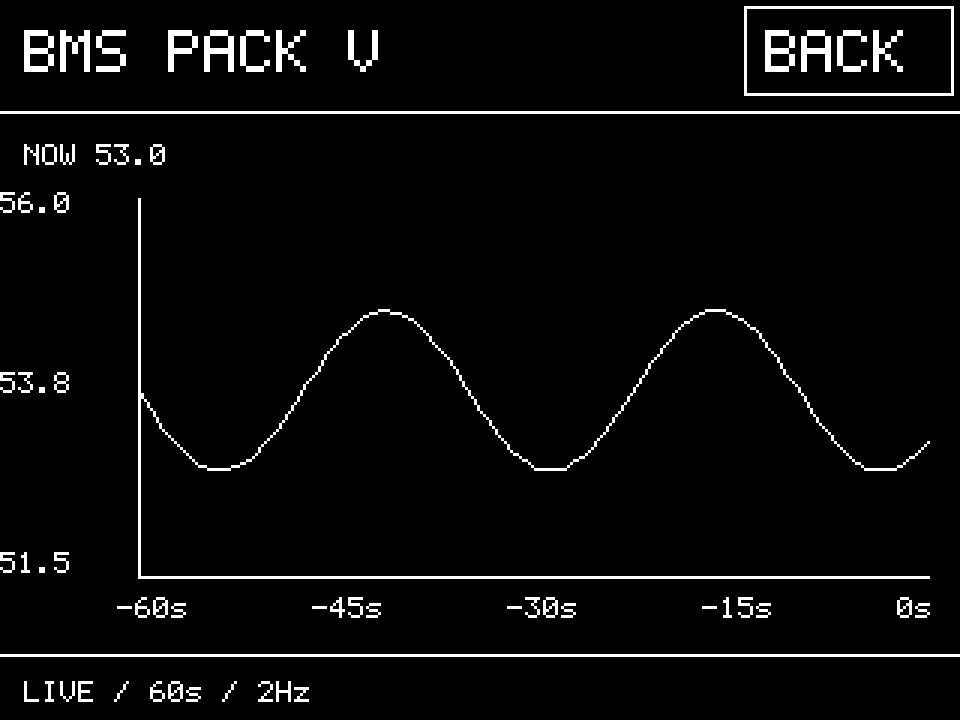
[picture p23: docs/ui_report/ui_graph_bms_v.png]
BMS 전압 그래프


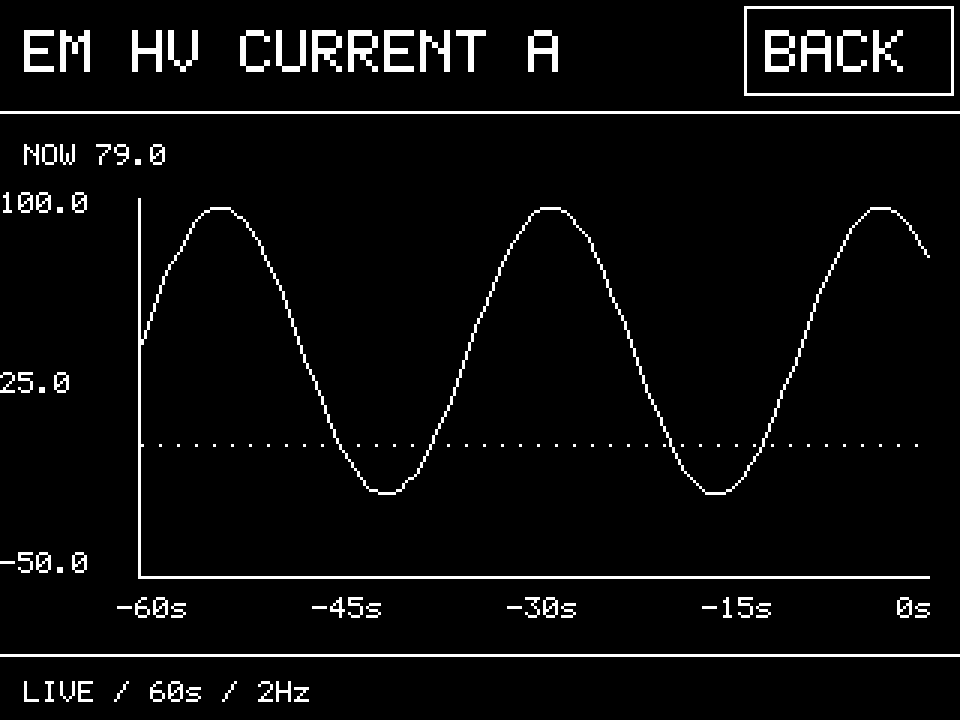
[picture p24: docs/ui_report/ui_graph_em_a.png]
EM HV 전류 그래프


스로틀 그래프

RTK는 숫자를 평균하지 않고 관측한 상태 변화 시점을 계단형으로 표시한다. NO DATA, NO FIX, GNSS, DGPS, FLOAT, FIXED, OTHER를 구분한다. 최근 상태 변화 최대 256개를 보관하며 한도 초과 시 덮어쓴 수를 표시한다.

RTK 상태 이력

## 5. 현재 기능의 한계

### LV SOC

현재 EM은 HV 전압·HV 전류·LV 전원 전압·CPU 온도를 보낸다. HV SOC도 EM이 아니라 BMS BLE에서 받는다. LV 배터리는 별도이며 현재 LV SOC를 제공하는 수신 항목이 없다.

LV 전압은 표시할 수 있지만, 그것만으로 실제 잔량 %를 결정할 수는 없다. 배터리 화학계·직렬 수·부하·온도 등의 영향을 받으며 현재 검증된 전압-SOC 관계나 LV 전류 적산 입력도 없다. 따라서 **HV에는 SOC 막대/%를 표시하고, LV에는 전압만 표시한다.** LV SOC 표시에는 별도 LV BMS의 SOC 또는 검증된 잔량 추정 체계가 필요하다.

### 브레이크

현재 수신하는 값은 VCU의 디지털 Brake Active뿐이다. 브레이크 압력 센서와 보정된 연속값이 없으므로 압력 막대나 bar/MPa 수치를 만들 수 없다. 유압 누설 우려가 있는 상태에서는 압력 센서 추가를 전제로 하지 않으며, 홈 화면에는 제동 입력 여부만 `BRK`로 표시한다.

### 에너지와 전력

HV/LV 전압 및 전력 표시는 현재 임시 EM Gateway의 `EM RECORD` 수신에 의존한다. 전력은 표시용 계산값이며 대회 공식 10 kW 판정값이 아니다. 향후 대회용 에너지미터와 프로토콜이 달라지거나 임시 게이트웨이를 제거하면 해당 수신·표시 경로도 다시 정리해야 한다. 충전/방전 방향은 실차에서 전류 부호를 반드시 대조해야 한다.

### 그래프와 고장 이력

그래프는 RAM 부담을 줄이기 위해 2 Hz, 최근 60초만 저장한다. 빠른 피크 분석과 장시간 기록은 TMA-1 로그를 사용해야 한다. 연결 및 고장 이력도 RAM에만 있어 전원이 꺼지면 사라지며 상용 ECU의 영구 DTC 저장을 대체하지 않는다.

### 수신 데이터 의존성

화면 갱신 목표는 20 Hz이지만 원천 센서와 CAN/BLE 갱신률보다 새로운 값이 빨리 생기는 것은 아니다. Steering은 정규화 값이며 실제 조향각이 아니고, IMU 축·부호와 WSS 보정은 차량 장착 상태에서 검증해야 한다. `-- WAIT`, `STALE`, `INVALID`, `UNKNOWN`은 0과 구분해서 해석해야 한다.

### PCB V3 입력과 출력

START_IN은 30 kΩ/10 kΩ 분압 회로를 거친 GPIO34 ADC 전압으로 판정한다. 1500 mV 이상을 ON, 1000 mV 이하를 OFF로 보고 20 ms 연속 상태를 확인한다. 화면의 전압은 원래 9~12 V 신호가 아닌 **분압 후 ADC 전압**이다. 현재는 상태 확인용이며 차량 시동 제어에는 사용하지 않는다.

VESS는 GPIO4에서 단일 반전 MOSFET 단을 거쳐 출력되므로 펌웨어에서 duty를 반전 보상한다. 외부 출력은 약 2 ms HIGH pulse, 50~100 Hz이며 스로틀 피드백을 우선하고 없으면 모터 목표전류, 차량속도 순서로 크기를 정한다. 실차 음량과 주파수 체감은 별도 확인이 필요하다.

## 6. 추가 CAN 정보 및 팀별 확인 사항

세부 전달문은 [추가 CAN 정보 및 실차 확인 사항](CAN_DATA_REQUIRED.md)에 별도로 정리했다.

- VCU: 브레이크 압력 신규 요청은 보류하고 기존 Brake Active를 사용한다. Steering/IMU/개별 WSS/제어 상태는 새 송신 요청 대신 차량 업로드 버전과 해석 기준을 확인한다.
- 전원/EM: 전류 부호, 설치 위치, LV 측정 지점, 실차 송신 주기, 충전 막대 기준을 확인한다.
- TMA-1: 새 센서·제어 상태, valid/life, EM RECORD/SYNC를 기존 decoder와 대조한다. Decoder 생성만으로 실차 수신 검증이 완료되는 것은 아니다.

## 7. 코드 변경과 검증

화면은 순수 렌더링 모듈, 이력은 고정 크기 저장 모듈, 실제 상태 연결은 `check_snapshot.cpp`로 나눴다. CAN 수신부에는 VCU Car Check v1 디코더를 추가했다. 기존 동적 WSS 기록 버퍼를 고정 이력 버퍼로 교체하고, 화면 갱신 태스크를 50 ms로 설정했다. LCD 전송 중 한꺼번에 들어오는 프레임을 보관하도록 CAN RX 대기열을 SDK 기본 5개에서 64개로 늘렸다. 글꼴에는 `*`, `>`, `?`, `|`, `_`를 추가했다. GPS 랩타이머에는 정지 시점의 경과시간과 출발 대기 상태를 저장하는 Pause 상태를 추가하고, Resume 시 랩 기준 시각을 보정하도록 변경했다.

주요 파일: `src/modules/diagnostics.*`, `diagnostic_graph.cpp`, `diagnostic_home.cpp`, `diagnostic_history.*`, `car_check_receiver.*`, `src/core/check_snapshot.*`, `src/core/app_wiring.cpp`, `src/core/can_bus.cpp`, `include/state.h`, `include/car_check_protocol.h`, `src/logic/font5x7.cpp`.

최신 검증 결과: 전체 native 테스트 **124개 통과**, 이 중 진단 기능 테스트 **29개 통과**, ESP32 빌드 성공. 구동계 RPM 결손·발산 판정, PCB V3 입력 매핑, START ADC 판정과 반전 VESS 출력을 포함해 빌드 및 단위 테스트를 확인했다.

| 메모리 항목 | 확인값 |
| --- | --- |
| ESP32 고정 이력 저장부 | 9,400 B, 약 9.2 KiB |
| 숫자 샘플 | 12개 수치 × 최대 121시점, valid 및 단절 표시 포함 |
| 이벤트 | 최근 32개, 전원 종료 시 초기화 |
| RTK 상태 변화 | 최대 256개, 최근 60초 상태를 표현할 기준점 포함 |
| 전체 정적 RAM | 81,036 B / 327,680 B, 24.7% |
| Flash | 1,107,481 B / 1,310,720 B, 84.5% |

정적 RAM 수치는 BLE·Wi-Fi와 CAN 대기열 등의 실행 중 heap 사용량을 포함한 전체 최고 사용량이 아니다. 기존 최대 96 KB 동적 WSS 버퍼 할당은 제거했다. 이력 크기는 컴파일 시 10 KiB 이하 조건으로 검사한다. D/F 카운터의 내부 누적값은 유지하고 화면에서는 999를 넘으면 `>999`로 축약한다.

실차에서의 터치 좌표·가독성, 실제 표시 주기, BLE/NTRIP 병행 안정성, 모터·EM 전류 부호, START 임계값, VESS 출력 파형과 구동계 경고 오탐은 별도 확인 대상이다. 최신 코드는 GitHub `dev` 브랜치의 `7591f0c`에 반영했다. 이번 검증은 빌드와 단위 테스트이며 실차 파손 로그 재생 또는 실제 차량 경고 검증은 수행하지 않았다.

입력 없는 기본 화면과 수치 범위 끝값도 렌더링하여 확인한다.

미수신 기본 화면

끝값 배치 확인용 화면

## 근거

- Cluster 현재 로컬 코드의 CAN 수신, BMS 적용, 화면 및 태스크 정의.
- [VCU Car Check v1 계약](https://github.com/2026-HEVEN/vcu/blob/8498e2f20cfa79f8c71416a25a2676677b59a270/docs/CAR_CHECK_CAN.md), 해당 커밋의 송신 코드 및 보드 핀 정의.
- PM의 EM RECORD/SYNC 사양, 제공된 `107signals (1).json`, `BMS·모터컨트롤러 전류 기반 10 kW 제한` 문서.

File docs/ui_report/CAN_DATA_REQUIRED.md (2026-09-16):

# 추가 CAN 정보 및 실차 확인 사항

기준: 이번 Cluster 로컬 구현과 VCU `dev`의 `8498e2f20cfa79f8c71416a25a2676677b59a270`에서 확인한 Car Check v1 계약. 다른 팀에 메시지를 발송하거나 VCU 코드를 변경한 것은 아니다.

## 1. VCU팀에 요청할 내용

현재 Cluster에는 Steering, IMU, 4륜 개별 휠 속도, TV·회생제동·Paddock 진단 프레임을 받는 기능을 연결했습니다. 아래 네 프레임을 새로 만들어 달라는 요청은 필요하지 않습니다. 실제 차량에 해당 송신 버전이 업로드되어 있는지 확인 부탁드립니다.

| CAN ID | 내용 | 이번 Cluster 처리 |
| --- | --- | --- |
| `0x1804C0D0` | 정규화 조향값, valid, life | 부호 있는 int16 ×0.001. 각도가 아님. |
| `0x1805C0D0` | Yaw rate, 가속도 X/Y, valid, life | int16 ×0.01. deg/s, g. |
| `0x1806C0D0` | FL/FR/RL/RR 개별 속도 | uint16 ×0.1 km/h, `0xFFFF`는 무효. |
| `0x1807C0D0` | 요청 수신값, 실제 제어 상태, 차단 이유 | v1 확인 후 표시. 요청과 적용을 구분. |

모두 Extended CAN, DLC 8, Little Endian, 공칭 50 ms/20 Hz이며, Cluster는 300 ms 초과 미수신 시 오래된 정보로 처리합니다. Steering/IMU의 유효성 표시 비트가 없는 구버전은 `UNKNOWN`으로 표시합니다.

추가 확인이 필요한 항목은 다음과 같습니다.

1. **브레이크 상태:** 브레이크 압력 센서 추가는 현재 보류합니다. 기존 `0x1801C0D0`의 Brake Active ON/OFF가 실제 페달/브레이크 스위치와 일치하는지만 확인해 주세요. Cluster는 이 bit가 유효할 때만 홈 화면에 `BRK`를 표시하며 압력값으로 해석하지 않습니다.
2. **조향/IMU 해석:** 조향 좌·우 부호, 정규화 양 끝의 실제 의미, IMU 설치 방향과 차량 X/Y/Z 축·yaw 부호를 공유해 주세요. 현재 물리 단위는 알지만 차량 장착 방향까지 확인된 것은 아닙니다.
3. **개별 휠 속도 유효성:** `0xFFFF` 처리 및 센서 고장 검출 조건, 타이어 둘레 보정이 실제 펌웨어와 일치하는지 확인해 주세요. 유효한 숫자 0이 수신된다는 것만으로 센서 배선 정상까지 입증되지는 않습니다.
4. **적용 상태 해석:** TV Active는 제어 경로와 출력 허용 상태, Regen Active는 반대 부호 명령의 활성 상태입니다. 실제 차동 토크 또는 배터리 충전 전력의 측정값과 같은 의미가 아님을 함께 확인해 주세요.

기어, 스로틀, 브레이크 ON/OFF, HV 활성, Paddock 상태 및 대표 WSS 차속은 기존 수신 경로를 사용합니다. 모터 전압·버스 전류·상 전류·RPM·온도·고장 정보는 모터컨트롤러 직접 송신값을 사용하므로 VCU에 중복 송신을 요청하지 않습니다.

## 2. 전원·에너지미터 담당 확인 사항

| 항목 | 현재 가능한 표시 | 추가 확인 또는 데이터 |
| --- | --- | --- |
| HV SOC | BMS BLE에서 받은 %와 막대 | 현재 BMS의 SOC 유효성 확인 |
| HV/LV 전압 | EM RECORD 수신 시 숫자와 이력 그래프 | LV 측정 지점이 LV 배터리 단자와 같은 전위인지 확인 |
| 전력 크기 | 동일 EM RECORD의 전압×전류 절댓값, kW | 공통 HV 경로 설치 여부, 실제 송신·수신 주기 |
| 충전/방전 방향 | 임시로 전류 0 이상=POWER, 0 미만=CHARGE | 알려진 구동·회생 조건에서 EM 전류 부호 확인. 반대이면 UI 매핑 변경 |
| 충전 막대 기준 | 아직 미확정 | 허용 충전 전력/전류와 별도 표시 범위 |
| LV SOC | 제공되지 않음 | 별도 LV BMS의 SOC 또는 검증된 잔량 추정 입력 필요 |

전압 한 값만으로 LV SOC를 정확한 %로 환산할 수 없습니다. 배터리 화학계·직렬 수·전압 곡선·부하/온도 영향 정보도 없으며, 현재 EM에는 LV 전류·용량·적산 SOC가 없습니다. 따라서 LV SOC 막대와 %를 생성하지 않습니다.

## 3. TMA-1 담당에게 전달할 내용

제공된 `107signals (1).json` 이후 갱신분과 대조해 아래 항목을 보완해 주세요. 이미 추가했다면 중복 생성할 필요는 없습니다. 이번 작업에서는 JSON을 수정하지 않았습니다.

| 대상 | Decoder 기준 |
| --- | --- |
| Steering | `1804C0D0`, Byte0~1 signed LE ×0.001, Byte6 bit0 valid, bit7 validity-present, Byte7 life |
| IMU | `1805C0D0`, Byte0~1 yaw, 2~3 ax, 4~5 ay: signed LE ×0.01. Byte6 bit0 yaw-valid, bit1 accel-valid, bit7 validity-present, Byte7 life |
| 개별 WSS | `1806C0D0`, Byte0~1 FL, 2~3 FR, 4~5 RL, 6~7 RR: unsigned LE ×0.1 km/h. `65535` raw는 invalid |
| Control | `1807C0D0`, Byte0 version=1, Byte1 bits0/1/2 TV/RGN/PDK 요청 수신값 |
| Control 적용 | 같은 ID Byte2 bit0 TV active, bit1 regen available, bit2 regen active, bit3 Paddock active, bit4 output allowed, bit5 Cluster fresh, bit6 brake sensor installed |
| Control 이유 | 같은 ID Byte3 TV 차단 비트, Byte4 regen 차단 비트, Byte7 life. 각 비트는 VCU 계약 문서 참조 |
| EM RECORD | `1CF5FFC1`, Byte0~1 HV V signed ×0.1, 2~3 HV A signed ×0.1, 4~5 LV V signed ×0.01, 6~7 CPU °C signed ×0.01, 모두 LE |
| EM SYNC | `1CF6FFC1`, Byte0~3 uptime uint32 ms, 4~5 record count uint16, Byte6 bits0 sd_ok/1 header_seen/2 uart_alive/3 drops, Byte7 life |
| 기존 항목 보완 | VCU 스로틀 valid/Paddock 적용 상태, BMS valid/BLE/life 및 Detail 프레임은 최신 기존 계약과 대조 |

Decoder만 추가되어 있다고 실차 수신이 확인된 것은 아닙니다. 수신 시각, valid, stale 및 invalid sentinel을 함께 해석해야 합니다. 조건부 필터를 지원하지 않는 도구에서는 분석 단계에서 무효 값을 제외해 주세요.

## 근거

- [VCU Car Check 계약](https://github.com/2026-HEVEN/vcu/blob/8498e2f20cfa79f8c71416a25a2676677b59a270/docs/CAR_CHECK_CAN.md)
- [VCU 송신 코드](https://github.com/2026-HEVEN/vcu/blob/8498e2f20cfa79f8c71416a25a2676677b59a270/src/core/can_bus.cpp)
- [VCU 입력 핀 정의](https://github.com/2026-HEVEN/vcu/blob/8498e2f20cfa79f8c71416a25a2676677b59a270/src/core/board_pins.h)
- Cluster `include/car_check_protocol.h`, `src/modules/car_check_receiver.cpp`, `src/core/check_snapshot.cpp`, `src/core/can_bus.cpp`.
- 사용자가 제공한 EM RECORD/SYNC 사양, `107signals (1).json`, `BMS·모터컨트롤러 전류 기반 10 kW 제한` 문서. 실제 설치·부호·주기는 실차 확인 대상으로 남겨 둡니다.

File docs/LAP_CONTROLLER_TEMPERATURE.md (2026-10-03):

# Lap controller temperature telemetry

## Scope

- Instantaneous controller temperature remains controller-origin FB2 data:
  Left `0x1802D0EF`, Right `0x1802D0F0`, byte 0 unsigned, multiplier 1,
  offset -40, Celsius. Cluster does not rebroadcast these instantaneous values.
- New Cluster statistics cover laps 1-51, independently for left and right.
- Existing lap-time/battery IDs and GPS start/crossing/pause/resume logic retain
  their meaning; those older telemetry features still support 99 laps internally.
- VCU LV voltage is received under the new mirrored `lv_monitor_protocol.h`
  contract. No estimated LV voltage or LV SOC is introduced.

## VCU LV supply voltage (dev integration)

Cluster dev `b8b201c` and VCU dev `36f03a0` share an identical LV contract.
VCU measures GPIO33 via a 3.3k/1k divider from `+12V_FUSED` and broadcasts
Extended `0x1C09C0D0`, DLC 8, every 100 ms (10 Hz). Cluster receives it directly,
without retransmission, and displays it as VCU LV VOLTAGE in Car Check power
details when valid and received within 500 ms. The local home-screen adapter
also shows LV directly below HV PACK voltage, right-aligned, with two decimal
places; unseen, invalid or older-than-500-ms samples show `-- V` instead.
HV voltage remains sourced from the BMS, independently of LV freshness.

| Bytes | Signal | Type | Multiplier | Offset |
| --- | --- | --- | --- | --- |
| 0-1 | LV supply voltage | uint16 LE | 0.01 V | 0 |
| 2-3 | ADC pin voltage | uint16 LE | 0.001 V | 0 |
| 4 bit 0 | Sample valid | bool | 1 | 0 |
| 5 | Sequence | uint8 | 1 | 0 |
| 6-7 | Reserved | - | - | - |

JSON adds VCU LV Supply Voltage (byte 0-1, unsigned LE, multiplier 0.01,
offset 0, unit Volt) and VCU LV Sample Valid (bit 32, unit State).
Voltage filter/mask: `0000000001000000` / `0000000001000000`, requiring
byte 4 bit 0. Example `B0 04 E7 0A 01 2A 00 00` means 12.00 V, ADC 2.791 V,
valid, sequence 42. A filtered invalid sample can leave Monolith's previously
held voltage visible until its UI timeout; inspect Sample Valid as well.

Important limits: ADC >=3100 mV is declared invalid, corresponding to input
>=13.33 V with the nominal divider. This can exclude normal battery charging
voltages and needs VCU/hardware-team review if the LV rail exceeds this level.
A zero ADC sample is considered usable by this firmware and does NOT prove
the measurement wiring is connected. These are diagnostic measurements, not
a battery SOC estimate or a safety gate. Real-voltage calibration remains a
vehicle/bench task.

## Calculation

Mean temperature is `sum(temperature_C * valid_running_ms) / valid_running_ms`.
Latest FB2 temperature is held until the next FB2 sample, for at most 300 ms.
The integral is updated on FB2 reception and GPS task polling. No frame means
no measurement: left and right validity are independent.

A mean is valid only after some covered time exists and at least 90% of the
observed timer-running interval has fresh temperature coverage. Missing/stale
intervals are not filled with zero and do not silently produce a full-lap mean.
The mean is computed from the covered part of an accepted lap, not a claim of
100% coverage. Temperature source resolution remains 1 C even though averages
and differences are encoded at 0.1 C.

`rise(lap N) = mean(lap N) - mean(lap N-1)` for the same controller.
Negative values mean cooling. Lap 1 has no valid rise. A missing/invalid previous
lap is not skipped: the next lap's rise also remains invalid for that side.
During a lap the running mean/rise updates; completed values are frozen.
These are differences between lap means, NOT within-lap start/end rises.

Start/Reset clears all statistics. Waiting for departure collects nothing.
Stop freezes them. Resume excludes paused time but continues the same lap.
Statistics begin when departure is confirmed and roll over when the GPS parser
detects a crossing. Unlike lap-time interpolation, temperature integration does
not retrospectively split samples at the interpolated crossing timestamp.
Boundary uncertainty includes the departure confirmation interval and the
GNSS reporting/parser latency; this is an analysis feature, not protection logic.

## CAN contract

Both frames: 29-bit Extended Classic CAN, DLC 8, little endian.
IDs are distinct from all IDs defined in this Cluster repository, including
the reset report `0x1CFDFFC0`; vehicle-wide allocation still needs coordination.

| ID | Name | Byte 2-3 | Byte 4-5 |
| --- | --- | --- | --- |
| `0x18FDFFC0` | Lap Controller Mean Temperature | Left mean x10 | Right mean x10 |
| `0x18FEFFC0` | Lap Controller Temperature Rise | Left rise x10 | Right rise x10 |

| Byte | Meaning |
| --- | --- |
| 0 | Lap number 1-51 |
| 1 bit 0 | Left mean valid |
| 1 bit 1 | Right mean valid |
| 1 bit 2 | Left rise valid |
| 1 bit 3 | Right rise valid |
| 1 bit 4 | Completed |
| 1 bit 5 | Active lap |
| 1 bit 6 | Timer running |
| 1 bit 7 | Timer paused |
| 2-3 | Left int16, 0.1 C/bit, offset 0 |
| 4-5 | Right int16, 0.1 C/bit, offset 0 |
| 6 | Same session byte as lap-time/battery telemetry |
| 7 | Same life counter as the corresponding lap-time/battery announcement |

Invalid raw is `INT16_MIN` (-32768, bytes `00 80`). Do not interpret it as a
temperature of -3276.8 C. Flags are authoritative.

Current lap: target 5 Hz. The latest nine completed laps: target 1 Hz each,
distributed over the second. The current lap plus those completed laps form
the recent ten-slot window. Older completed laps: target 0.1 Hz each, spread
over ten seconds. On lap 11, lap 1 slows down; on lap 12, lap 2 also slows down.
Final announcements follow the existing repeated-final path. Start/Reset still
clears the previous session. CAN congestion can delay these target rates.
Frames for mean and rise are transmitted with the corresponding lap history
announcement. A bounded 16-packet queue retries TWAI enqueue failures without
blocking, and drains at most four packets per 5 ms service. Prolonged CAN
congestion/offline operation can reduce rates; this is not guaranteed delivery.
Old pending packets are discarded on a session change.

## Monolith decoder settings

| Name (N=1..51) | ID | Unit | Multiplier | Offset | Bytes | Signed | Endian |
| --- | --- | --- | --- | --- | --- | --- | --- |
| Lap N Time | `18FBFFC0` | Second (s) | 0.001 | 0 | 2-5 | No | Little |
| Lap N Left Controller Mean Temp | `18FDFFC0` | Lap Controller Mean Temperature (C) | 0.1 | 0 | 2-3 | Yes | Little |
| Lap N Right Controller Mean Temp | `18FDFFC0` | Lap Controller Mean Temperature (C) | 0.1 | 0 | 4-5 | Yes | Little |
| Lap N Left Controller Temp Rise | `18FEFFC0` | Lap Controller Temperature Rise (C) | 0.1 | 0 | 2-3 | Yes | Little |
| Lap N Right Controller Temp Rise | `18FEFFC0` | Lap Controller Temperature Rise (C) | 0.1 | 0 | 4-5 | Yes | Little |

Filters are payload-byte hex strings, using the same ordering as the supplied
Monolith JSON. `NN` means the lap number encoded as two hex digits (lap 51=33).

| Signal | Data Filter | Data Mask |
| --- | --- | --- |
| Time | `NN00000000000000` | `ff00000000000000` |
| Left mean | `NN01000000000000` | `ff01000000000000` |
| Right mean | `NN02000000000000` | `ff02000000000000` |
| Left rise | `NN04000000000000` | `ff04000000000000` |
| Right rise | `NN08000000000000` | `ff08000000000000` |

Example completed lap 2, left mean 53.3 C, right mean unavailable,
left rise -3.3 C, session 7, life 12:

```text
18FDFFC0: 02 15 15 02 00 80 07 0C
18FEFFC0: 02 15 DF FF 00 80 07 0C
```

Invalid temperatures and first-lap rises do not match their decoder filters.
Monolith may retain its last decoded value after a reset until its own display
timeout; an invalid/reset packet cannot force a conditional decoder to show
blank. Session separation must also be respected when interpreting saved logs.
The files preserve the supplied time/battery reset filtering behavior and
unrelated channels, except the obsolete EM LV decoder is removed to avoid
confusing it with the new VCU LV source. Some broad profiles retain other
legacy EM channels from the originals; these may be hidden/removed in Control
Hub if the energy meter is absent. Existing GNSS or
other decoder correctness was not re-audited as part of this temperature change.

## Generated configurations

Run `tools/update_monolith_lap_temperature.py` with an input directory containing
the three supplied files and an output directory. Originals are never modified.
Outputs in `docs/monolith/lap51/`:

- `316signals_RaceMonitor_Lap51_ControllerTemperature.json`
- `348signals_Field_Lap51_ControllerTemperature.json`
- `434signals_Full_Lap51_ControllerTemperature.json`

Each contains 51 lap-time signals, 51 existing battery-use signals, 102 lap
controller-mean signals and 102 rise signals, two VCU LV signals, plus its
original non-lap channels.
All lap-numbered signals above 51 are removed. JSON syntax, unit references and
temperature validity-filter matching are checked by the generator. Control Hub
import, live radio throughput and plotting hundreds of channels require a real
device check; firmware compilation is not proof of those UI behaviors.

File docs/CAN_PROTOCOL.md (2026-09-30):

# HEVEN CAN 프로토콜 명세서 (단일 출처)

> **이 문서는 VCU·Cluster 양 레포가 공유하는 단일 출처(single source of truth)입니다.**
> 코드(`include/can_protocol.h`)와 이 문서는 항상 일치해야 하며, 수정 시 **양 레포에 동일하게 반영**합니다. (담당: 김도현)
> 출처: `EZkontrol-CANBUS-MCU-to-VCU.pdf V1.0`, `EZkontrol-CANBUS-MCU-to-METER.pdf V1.1`, 시스템 설계.

---

## 1. 버스 파라미터

| 항목 | 값 |
|---|-----|
| 비트레이트 | **250 kbps** |
| 프레임 | CAN 2.0B **확장(29비트) 식별자** |
| 바이트 순서 | **리틀엔디언** (예: 0x1234 → 0x34 먼저, 0x12 나중) |
| 토폴로지 | 데이지체인, 양 끝단 120Ω 종단 |
| 표준 | SAE J1939 기반 |

---

## 2. 29비트 식별자 구조 (J1939)

```
 28..26   25   24   23..16     15..8       7..0
┌────────┬────┬────┬────────┬──────────┬────────────┐
│PRIORITY│ R  │ DP │  PF    │   PS     │     SA     │
│ 3bit   │ 0  │ 0  │ 8bit   │  8bit    │   8bit     │
└────────┴────┴────┴────────┴──────────┴────────────┘
```
- **PRIORITY**: 0~7 (값 작을수록 우선). 제어명령=3, 피드백=6.
- **PF (PDU Format)**: 메시지 종류. PF<240이면 PS=목적지 주소(DA), PF≥240이면 PS=그룹확장.
- **PS**: 목적지 노드 주소 (PF<240일 때).
- **SA**: 송신 노드 주소.

> 예) `0x0C01EFD0` → PRIORITY=3, PF=0x01, PS=0xEF(MCU1 목적지), SA=0xD0(VCU 송신).
> 즉 **"VCU가 MCU1에게 보내는 1번 메시지"**.

---

## 3. 노드 주소 (SA)

### HEVEN 시스템에서 실제 사용

| 노드 | SA (HEX) | SA (DEC) | 비고 |
|---|---|---|---|
| Energy_Meter / **METER** | 0x17 | 23 | EZkontrol 표준 계기 주소 |
| **Cluster_ESP32** | 0xC0 | 192 | 계기판 HMI (시스템 설계) |
| **VCU_ESP32** | 0xD0 | 208 | 차량 제어 |
| **Controller_L (MCU1)** | 0xEF | 239 | 좌측 모터컨트롤러 (기본값) |
| **Controller_R (MCU2)** | 0xF0 | 240 | 우측 — **EZkontrol 앱에서 SA=0xF0 수동 설정 필요** |

### EZkontrol 표준 전체 주소표 (참고)

| 노드 | 주소 |
|---|---|
| METER | 23 (0x17) |
| VCU | 208 (0xD0) |
| MCU1~4 | 239~242 (0xEF~0xF2) |
| BMS1~4 | 243~246 (0xF3~0xF6) |
| GLOBAL | 255 (0xFF) |

> **N.B.** MCU의 SA는 호스트(EZkontrol 앱)에서 "controller number"로 설정. 기본 SA = 239(0xEF).
> Controller_R은 반드시 240(0xF0)으로 바꿔야 좌우가 충돌하지 않음.

---

## 4. 메시지 ID 일람 (HEVEN)

| 방향 | 메시지 | Controller_L (0xEF) | Controller_R (0xF0) | 주기 | Prio |
|---|---|---|---|---|---|
| VCU → MCU | 제어명령 / 핸드셰이크응답 | `0x0C01EFD0` | `0x0C01F0D0` | 50ms | 3 |
| MCU → VCU | 피드백 Part I (전압/전류/속도) | `0x1801D0EF` | `0x1801D0F0` | 50ms | 6 |
| MCU → VCU | 피드백 Part II (온도/상태/에러) | `0x1802D0EF` | `0x1802D0F0` | 50ms | 6 |
| MCU → METER | 계기 메시지 I | `0x180117EF` | `0x180117F0` | 100ms | 6 |
| MCU → METER | 계기 메시지 II | `0x180217EF` | `0x180217F0` | 100ms | 6 |
| Cluster → VCU | 커맨드 (패독/TC/회생 Auto/디버그) | `0x1801D0C0` (신규) | — | ~20ms | 6 |
| VCU → Cluster/TMA-1 | 단일 차량속도 | `0x1803C0D0` (신규) | — | 50ms | 6 |
| Cluster → TMA-1/logger | BMS 상태 요약 | `0x18F3FFC0` (신규) | — | 100ms | 6 |
| Cluster → TMA-1/logger | BMS 상세 요약 | `0x18F4FFC0` (신규) | — | 100ms | 6 |
| Cluster → TMA-1/logger | GNSS Ground Speed + RTK 품질 | `0x18F9FFC0` (신규) | — | 새 RMC마다 | 6 |
| Cluster → logger | 루프 타이밍 진단 | `0x18FAFFC0` (신규) | — | 1s | 6 |

> ID에서 PS(목적지)·SA(송신)만 컨트롤러별로 바뀜. 위 표의 ID는 `PF<<16 | PS<<8 | SA`로 조립됨(+ Priority).

---

## 5. 메시지 상세

### 5.1 VCU → MCU : 제어명령  `0x0C01EFD0` (L) / `0x0C01F0D0` (R) · 50ms

| 바이트 | 항목 | 분해능 | 오프셋 | 범위 |
|---|---|---|---|---|
| 0~1 | Target Phase Current (토크) | 0.1 A/bit | −3200 A | −3200~3200 A |
| 2~3 | Target Speed | 1 rpm/bit | −32000 | −32000~32000 rpm |
| 4 | Command Controls | — | — | bit0: 0=HALTED / 1=RUNNING<br>bit1: 0=토크모드 / 1=속도모드<br>bit7-2: 예약 |
| 5,6 | 예약 | — | — | 0 |
| 7 | Life signal | — | — | 0~0xFF (매 프레임 +1) |

**토크 스케일링**: `raw16 = (target_A + 3200) × 10` (리틀엔디언). 음수 = 회생제동.
→ 0A=32000, +32A=32320, −32A=31680. **`include/can_protocol.h`의 `torque_to_raw()`와 동일.**

### 5.2 VCU → MCU : 핸드셰이크 응답  `0x0C01EFD0` / `0x0C01F0D0`

8바이트 **전부 `0xAA`**. (MCU의 0x55 요청에 대한 응답 — §6 참고)

### 5.3 MCU → VCU : 피드백 Part I  `0x1801D0EF` (L) / `0x1801D0F0` (R) · 50ms

| 바이트 | 항목 | 분해능 | 오프셋 | 범위 |
|---|---|---|---|---|
| 0~1 | Bus Voltage | 0.1 V/bit | 0 | 0~300 V |
| 2~3 | Bus Current | 0.1 A/bit | −3200 A | −3200~3200 A |
| 4~5 | Phase Current | 0.1 A/bit | −3200 A | −3200~3200 A |
| 6~7 | Speed | **1 rpm/bit** | −32000 | −32000~32000 rpm |

### 5.4 MCU → VCU : 피드백 Part II  `0x1802D0EF` (L) / `0x1802D0F0` (R) · 50ms

| 바이트 | 항목 | 분해능 | 오프셋 |
|---|---|---|---|
| 0 | Controller Temperature | 1 ℃/bit | −40 ℃ |
| 1 | Motor Temperature | 1 ℃/bit | −40 ℃ |
| 2 | STATUS — bit0: HALTED/RUNNING, bit1: 토크/속도모드 | — | — |
| 3 | ERROR1 비트맵 (아래) | — | — |
| 4 | ERROR2 비트맵 (아래) | — | — |
| 5 | ERROR3 비트맵 (아래) | — | — |
| 6 | 예약 | — | — |
| 7 | Life signal | — | 0~0xFF |

**ERROR 비트맵** (각 비트 0=정상 / 1=에러):
- **Byte3**: 0 과전류, 1 과부하, 2 과전압, 3 저전압, 4 컨트롤러과열, 5 모터과열, 6 모터스톨, 7 모터결상
- **Byte4**: 0 모터센서, 1 모터보조센서, 2 엔코더정렬불량, 3 폭주방지작동, 4 메인가속, 5 보조가속, 6 프리차지, 7 DC컨택터
- **Byte5**: 0 전력밸브, 1 전류센서, 2 오토튠, 3 RS485, 4 CAN, 5 소프트웨어

### 5.5 MCU → METER : 계기 메시지 I  `0x180117EF` · 100ms

> Cluster가 METER(0x17)로 동작할 때 직접 수신 (§7 경로 결정 참고).

| 바이트 | 항목 | 분해능 | 오프셋 |
|---|---|---|---|
| 0~1 | Bus Voltage | 0.1 V/bit | 0 |
| 2~3 | Bus Current | 0.1 A/bit | −3200 A |
| 4~5 | Phase Current | 0.1 A/bit | −3200 A |
| 6~7 | Speed | **0.1 rpm/bit** ⚠️ | −32000 |

> ⚠️ **METER 경로의 Speed는 0.1rpm/bit** — VCU 경로(5.3, 1rpm/bit)와 분해능이 다르다. 혼동 주의.
> (PDF 본문의 PS 표기 "0x11"은 오타이며, ID값 `0x180117EF`가 정답 — PS=0x17=METER.)

### 5.6 MCU → METER : 계기 메시지 II  `0x180217EF` · 100ms

| 바이트 | 항목 | 분해능/의미 |
|---|---|---|
| 0 | Controller Temperature | 1 ℃/bit, offset −40 |
| 1 | Motor Temperature | 1 ℃/bit, offset −40 |
| 2 | Accelerator Opening | 1 %/bit (0~100%) |
| 3 | STATUS — bit2-0 Gear(0:N/A,1:R,2:N,3:D1,4:D2,5:D3,6:S,7:P), bit3 Brake(0/1), bit6-4 Operation Mode(2:Cruise,3:EBS,4:Hold), bit7 DC Contactor(0:OFF/1:ON) | — |
| 4 | ERROR1 (5.4 Byte3과 동일 비트맵) | — |
| 5 | ERROR2 (5.4 Byte4와 동일) | — |
| 6 | ERROR3 (5.4 Byte5와 동일) | — |
| 7 | bit7-4: Life signal | 0~0xFF |

### 5.7 Cluster → VCU : 커맨드  `0x1801D0C0` (신규 할당) · ~20ms

> 계기판 config 입력(패독·TC·회생제동)을 VCU에 전달. **EZkontrol 표준이 아닌 HEVEN 자체 정의.**
> 기어 스위치는 Cluster ESP32에 직접 연결하지 않고 VCU 쪽 ADC/pass-through 회로에서 읽는다.
> PF=0x01, PS=0xD0(VCU), SA=0xC0(Cluster). MCU→VCU(0x1801D0EF)와 SA로 구분되어 충돌 없음.
> 인코딩 구현: Cluster 펌웨어 `encode_cluster_command()`. 아래 레이아웃과 일치.

| 바이트 | 항목 | 의미 |
|---|---|---|
| 0 | Reserved | 0 |
| 1 | Config flags | bit0: TV enable, bit1: Regen Auto enable(`Cluster RGN 1~3`이면 1, `RGN 0`이면 0), bit2: reserved(0), bit3: Debug legacy request(PCB V3에는 스위치가 없어 0), bit7-4: reserved(0) |
| 2 | Flags | bit0: Paddock request, bit7-1: reserved(0) |
| 3~7 | 예약 | 0 |

> ⚠️ 패독은 **요청 신호**일 뿐. VCU가 토크/속도를 상한 이하로 클램프하고 CAN 끊김 시 fail-safe(제한 유지)를 결정해야 함.
> ⚠️ 회생제동 토글도 **요청 신호**다. bit1=1이면 VCU 자동 회생제동 허용, bit1=0이면 회생제동 OFF 요청으로 해석한다. 실제 회생 전류와 차단 여부는 VCU가 배터리 전압/SOC/BMS fault/속도 조건을 기준으로 최종 제한해야 한다.
> 회생제동은 PCB V3 로터리 스위치 GPIO36(bit0), GPIO39(bit1)의 active-low 입력으로 결정한다. 두 핀 모두 입력 전용이므로 외부 풀업을 사용한다. 0단은 OFF, 1~3단은 ON이며 부팅 시에도 실제 스위치 위치를 따른다. RGN은 Car Check에서 ON/OFF 요청 상태로 표시하며 기본 화면에서는 표시하지 않는다.
> PCB V3 배선: TV GPIO32, Paddock GPIO33, HOME GPIO19, GPS LAP GPIO5, VESS PWM GPIO4이다. HOME은 Cluster 내부 기능으로 CAN 요청을 보내지 않는다.
> VCU/토크벡터링팀 인계: TV 스위치 요청은 기존 0x1801D0C0 Byte1 bit0을 그대로 사용하며 VCU에서 실제 적용 여부를 확인해야 한다. 회생제동 요청은 동일 프레임 Byte1 bit1로 0단=0, 1~3단=1을 송신한다(강도 3단계 구분 없음).
> VESS는 CAN 커맨드에 싣지 않는다. Cluster GPIO4는 PCB V3의 단일 반전 MOSFET 앞에서 50Hz PWM을 출력한다. GPIO4의 Low 폭은 1~2ms이며 반전 후 RX-TH에는 같은 폭의 High 펄스가 전달된다. 현재 구현은 VCU throttle feedback을 우선 사용하고, 없으면 모터 target current/차량속도 순서로 fallback하며 출력 펄스폭을 결정한다.

### EM Gateway 전압 표시 (2026-09-07)

- EM Gateway SA: `0xC1`. `0x1CF5FFC1` RECORD는 Extended, DLC 8, 10ms 주기이다.
- Byte0~1: signed int16 LE, HV bus voltage ×0.1V. Byte4~5: signed int16 LE, LV supply voltage ×0.01V. 영점 보정을 중복 적용하지 않는다.
- Cluster는 RECORD를 수신만 하며 재송신하지 않는다. 마지막 RECORD 수신 후 500ms 초과 또는 미수신이면 전압은 `-- V`로 표시한다. 실제 0V는 숫자로 표시한다.
- `0x1CF6FFC1` SYNC는 ID만 예약하며 이번 전압 표시는 RECORD 수신 시각을 사용한다. SD 기록 상태와 전압 유효성을 혼동하지 않는다.
- 기본 화면: HV/RGN 네모를 제거하고 HV SOC 글귀와 14×64px 게이지를 위로 이동한다. 퍼센트를 유지하고 HV/LV 전압 숫자는 2배 크기로 표시한다(범위를 벗어날 만큼 긴 문자열은 1배로 축소). LV SOC와 LV 게이지는 표시하지 않는다. HV SOC는 BLE BMS의 유효한 최근 값(5초 이내)을 사용한다.
- Car Check의 HV 상태는 기존 VCU HV active 비트로 표시한다. RGN은 Cluster 회생제동 요청 상태로서 VCU 적용 확인값이 아니다. EM bus voltage 및 BMS SOC는 서로 다른 측정 지점/원천임에 유의한다.
- VCU팀 인계: SA_EM_GW 및 CAN_ID_EM_RECORD/CAN_ID_EM_SYNC 정의를 VCU 공유 헤더에도 반영 필요. 이번 작업은 Cluster 저장소만 변경했다.
- 배선팀 인계: Cluster에 별도 전압 ADC 배선은 필요 없으며 EM Gateway와 기존 250kbps CAN 버스를 공유한다. LV 전압은 EM 공급전압 측정 지점의 값이다.

### 5.8 VCU → Cluster : 표시 상태  `0x1801C0D0` (HEVEN 정의) · 50~100ms 권장

> Cluster가 스위치 입력값이 아니라 **VCU가 확정한 차량 상태**를 표시하기 위한 프레임.
> 현재 Cluster 펌웨어는 이 프레임이 들어오면 기어/HV/브레이크/throttle/VCU-confirmed paddock 상태를 갱신한다. SOC는 선택 사항이며, 현재 주 경로는 Cluster의 BLE BMS 직접 수신이다.
> VCU 쪽 구현 전에는 Cluster가 기어를 확정할 수 없으므로 기본 N 표시로 남는다.

| 바이트 | 항목 | 의미 |
|---|---|---|
| 0 | Gear display | 0:N, 1:R, 2:D, 3:P |
| 1 | Flags | bit0: Brake, bit1: HV active, bit2: SOC valid, bit3: Throttle valid, bit4: Paddock active, bit7-5: reserved(0) |
| 2 | SOC percent | 0~100, bit2(SOC valid)=1일 때만 유효 |
| 3 | Throttle percent | VCU에서 보정·클램프한 0~100%, bit3(Throttle valid)=1일 때만 유효 |
| 4~6 | 예약 | 0 |
| 7 | Life signal | 0~0xFF |

> BMS SOC는 현재 `LWS-1608` BLE BMS를 Cluster ESP32가 직접 polling해서 표시한다.
> VCU가 추후 SOC를 확정값으로 보내야 하는 경우에만 이 프레임의 `SOC valid`와 `SOC percent`를 사용한다. VCU 프레임에서 SOC valid가 0이어도 BLE로 받은 SOC는 지우지 않는다.
> `Paddock active`는 Cluster의 요청 스위치가 아니라 VCU가 실제 패독 제한을 적용 중인지 확인하는 피드백이다. Cluster는 이 값으로 CAR CHECK 화면의 `PDK ON/OFF`를 표시하고, 상태 프레임 timeout 시 OFF로 복귀한다.

### 5.9 VCU → Cluster/TMA-1 : 단일 차량속도 `0x1803C0D0` (HEVEN 정의) · 50ms

> VCU의 `vehicle_speed_compute()`가 산출한 단일 차량속도를 Cluster LCD 표시와 TMA-1 Control Hub 그래프/로깅용으로 전달한다.
> 이 값은 전륜 기준 보정 로직을 거친 대표 차속이며, Cluster는 다시 네 바퀴 평균을 계산하지 않는다.
> 300ms 이상 수신되지 않거나 valid flag가 0이면 Cluster 표시 속도는 0km/h로 내려간다.

| 바이트 | 항목 | 분해능/의미 |
|---|---|---|
| 0~1 | Vehicle speed | uint16 little-endian, km/h x 10 |
| 2 | Valid flag | 1=valid, 0=invalid |
| 3~7 | Reserved | 0 |

구현 위치:
- VCU 인코딩: `encode_vcu_vehicle_speed()`
- VCU 송신: `can_bus::send_vehicle_speed()`
- Cluster 수신: `can_bus::poll_rx()`의 `CAN_ID_VCU_VEHICLE_SPEED` 처리

### 5.10 Cluster → TMA-1/logger : BMS 상태 요약 `0x18F3FFC0` (HEVEN 정의) · 100ms

> Cluster가 BLE로 직접 수신한 LWS-1608 BMS 표시용 정보를 TMA-1/logger에 전달한다.
> 이 프레임은 **차량 제어용 안전판단에 사용하지 않는다.** BLE가 끊기면 valid bit가 0으로 내려가며, 수신기는 해당 값을 stale/display-only로 취급한다.
> PF=0xF3, PS=0xFF, SA=0xC0. Broadcast 성격이므로 TMA-1/logger는 버스에서 수신만 하면 된다.

| 바이트 | 항목 | 분해능/의미 |
|---|---|---|
| 0 | Flags | bit0: BMS data valid, bit1: BLE connected, bit7-2: reserved(0) |
| 1 | SOC | 1 %/bit, 0~100 |
| 2~3 | Pack voltage | 0.1 V/bit, little-endian |
| 4~5 | Pack current | 0.1 A/bit, offset −3200 A, little-endian |
| 6 | BMS temperature | 1 ℃/bit, offset −40 ℃ |
| 7 | Life signal | 0~255 |

### 5.11 Cluster → TMA-1/logger : BMS 상세 요약 `0x18F4FFC0` (HEVEN 정의) · 100ms

| 바이트 | 항목 | 분해능/의미 |
|---|---|---|
| 0 | Flags | bit0: BMS data valid, bit1: BLE connected, bit7-2: reserved(0) |
| 1 | SOH | 1 %/bit, 0~100 |
| 2~3 | Remaining capacity | 1 mAh/bit, little-endian |
| 4~5 | Cycle count | 1 cycle/bit, little-endian |
| 6 | Reserved | 0 |
| 7 | Life signal | 0~255 |

### 5.12 Cluster → TMA-1/logger : GNSS Ground Speed `0x18F9FFC0` (HEVEN 정의) · RMC event-driven

> ZED-F9P의 유효한 NMEA RMC 문장에서 Speed Over Ground를 읽어 `knot × 1.852`로 km/h로 변환한다. Cluster가 위·경도 차분으로 속도를 다시 계산하는 방식이 아니다.
> 새 RMC 문장을 처리할 때마다 한 번 송신하므로 송신률은 ZED-F9P의 RMC 출력률을 따른다. 현재 약 5 Hz이며 펌웨어에 5 Hz로 고정하지 않는다.
> GNSS, RTK FLOAT, RTK FIXED 상태에서 모두 송신하며 status flags로 당시 위치해 품질을 함께 기록한다. `speed valid=0`이면 Byte0~1의 0을 실제 정지 속도로 해석하지 않는다.

| 바이트 | 항목 | 분해능/의미 |
|---|---|---|
| 0~1 | GNSS ground speed | uint16 little-endian, 0.01 km/h/bit |
| 2 bit0 | RMC fresh | 마지막 RMC가 3초 이내이면 1 |
| 2 bit1 | GPS fix valid | 최신 RMC status가 Active이고 fresh이면 1 |
| 2 bit2 | RTK FLOAT | GGA fix quality=5이면 1 |
| 2 bit3 | RTK FIXED | GGA fix quality=4이면 1 |
| 2 bit4 | Speed valid | RMC 속도 필드가 유효하고 GPS fix가 유효하면 1 |
| 2 bit5~7 | Reserved | 0 |
| 3 | GGA fix quality | NMEA GGA 원본 quality 값 |
| 4~5 | RMC age | uint16 little-endian, 0.1 s/bit, 미수신/포화=`0xFFFF` |
| 6 | Reserved | 0 |
| 7 | Life counter | 프레임 송신마다 1 증가, uint8 wraparound |

Monolith에서 실제 속도 채널은 Byte0~1에 multiplier `0.01`, offset `0`, unsigned, little-endian을 적용한다. 데이터 품질 확인용 bit decoder를 별도로 추가하고, 분석 시 `Speed Valid=1`인 구간을 사용한다. RTK 기반 구간만 보려면 `RTK FIXED=1`을 추가 조건으로 사용한다.

---
### 5.13 Cluster → logger : 루프 타이밍 진단 `0x18FAFFC0` (HEVEN 정의) · 1 Hz

> 메인 루프가 오래 막히면 화면·터치·CAN 수신이 늦어진다. 원인 작업을 주행 로그에서 찾기 위한 진단 프레임이다.
> 모든 값은 직전 프레임 이후 1초 창의 값이며, 송신 후 초기화된다.
> 커맨드 `0x1801D0C0`은 루프가 아니라 전용 태스크(코어 1, 우선순위 3, 20ms)에서 송신한다. 그래서 루프가 막혀도 커맨드 주기는 유지되어야 하며, Byte5~6으로 이를 확인한다.

| 바이트 | 항목 | 분해능/의미 |
|---|---|---|
| 0 | 가장 오래 걸린 스케줄러 작업 번호 | `g_tasks` 순서(0=can_rx, 1=gps, … 14=display, 15=이 프레임) |
| 1~2 | 그 작업의 최장 실행시간 | uint16 little-endian, 1 ms/bit |
| 3~4 | 최장 루프 정체 | uint16 little-endian, 1 ms/bit. 200 Hz CAN 수신 작업 사이 최대 간격 |
| 5 | 커맨드 최장 송신 간격 | uint8, 1 ms/bit, 255 포화 |
| 6 | 40 ms 넘게 늦은 커맨드 수 | uint8, 255 포화 |
| 7 | Life counter | 프레임 송신마다 1 증가 |

시리얼 콘솔 `timing` 명령은 작업별 최장·평균 실행시간과 실행 횟수를 출력하고 초기화한다.
---

## 6. 핸드셰이크 & 타임아웃 (EZkontrol 규칙)

```
[전원 ON]
   │  MCU가 0x1801D0EF 로 8바이트 0x55 를 50ms(20Hz)마다 송신
   ▼
VCU가 0x55 수신 ──► VCU가 0x0C01EFD0 로 8바이트 0xAA 응답
   │
   ▼  핸드셰이크 성립
MCU: 메시지 I·II 송신 시작 + VCU 제어명령(메시지 I) 대기·실행
```

**통신 실패 판정 (MCU 측):**
- VCU 제어명령(0x0C01EFD0)을 **10회 연속** 못 받거나
- Life signal **5회 연속** 실패

→ MCU 셧다운 후 핸드셰이크 재시도. (그래서 VCU는 50ms 라이프/제어 프레임을 **절대 끊지 말 것** — 펌웨어의 전용 FreeRTOS 라이프 태스크가 이를 보장.)

---

## 7. 계기 데이터 수신 경로 — **확정: C. VCU 모드 수신 스니핑**

EZkontrol 컨트롤러는 **METER 모드**일 때 피드백을 `0x1801xxEF`(VCU용)가 아니라
`0x180117EF`/`0x180217EF`(METER용, §5.5/5.6)로 보낸다.

~~A. Cluster=METER 직수신~~ / ~~B. VCU 게이트웨이~~ 대신 다음 경로로 확정:

**C. 컨트롤러를 VCU 모드로 설정 → Cluster가 그 VCU행 프레임(`0x1801D0EF/F0`, `0x1802D0EF/F0`)을 같은 버스에서 그대로 수신(스니핑)한다.**

- CAN은 멀티드롭 버스라 VCU 목적지로 보낸 프레임도 버스에 물린 모든 노드(Cluster 포함)에 물리적으로 도달한다.
  Cluster는 그 프레임을 **읽기만** 하면 되고, VCU의 게이트웨이 재방송이나 컨트롤러의 METER 모드 설정이 필요 없다.
- **필수 사전조건**: 두 컨트롤러 모두 EZkontrol 앱에서 VCU 모드로 설정, Controller_R은 SA=0xF0으로 설정.
  (METER 모드로 남아있으면 Cluster는 아무 것도 못 받는다 — `0x1801D0xx`가 아니라 `0x180117xx`로 나가기 때문.)
- Cluster는 컨트롤러 피드백을 **재방송하지 않고 읽기만** 한다. 단, 자체 HMI/BMS 정보는 별도 HEVEN 정의 프레임(`CAN_ID_CLUSTER_CMD`, `CAN_ID_CLUSTER_BMS_STATUS`, `CAN_ID_CLUSTER_BMS_DETAIL`)으로 송신한다.
- 구현: `src/core/can_bus.cpp`의 `poll_rx()`가 `CAN_ID_FB1_L/R`, `CAN_ID_FB2_L/R`을 필터링해 `state`의 `_r` 접미사 필드(Controller_R)와 기본 필드(Controller_L)에 각각 채운다.
- 기어/HV처럼 VCU가 최종 확정해야 하는 표시값은 `CAN_ID_VCU_CLUSTER_STATUS`(0x1801C0D0)를 통해 받는다. SOC는 현재 BLE BMS 직접 수신을 우선 사용한다.

---

## 8. 코드 매핑 (`include/can_protocol.h`)

현재 구현된 것:
```cpp
constexpr uint32_t CAN_ID_TORQUE_L = 0x0C01EFD0;  // VCU→MCU1
constexpr uint32_t CAN_ID_TORQUE_R = 0x0C01F0D0;  // VCU→MCU2
uint16_t torque_to_raw(float amps);   // (amps+3200)*10
float    raw_to_torque(uint16_t raw);
// SA 상수: SA_VCU=0xD0, SA_CLUSTER=0xC0, SA_CONTROLLER_L=0xEF, SA_CONTROLLER_R=0xF0, SA_ENERGY_METER=0x17

// 피드백 ID (VCU행 프레임을 Cluster가 스니핑, §7)
constexpr uint32_t CAN_ID_FB1_L = 0x1801D0EF;   // Part I (전압/전류/속도)
constexpr uint32_t CAN_ID_FB2_L = 0x1802D0EF;   // Part II (온도/상태/에러)
constexpr uint32_t CAN_ID_FB1_R = 0x1801D0F0;
constexpr uint32_t CAN_ID_FB2_R = 0x1802D0F0;
constexpr uint32_t CAN_ID_CLUSTER_CMD = 0x1801D0C0;
constexpr uint32_t CAN_ID_VCU_CLUSTER_STATUS = 0x1801C0D0;
constexpr uint32_t CAN_ID_VCU_VEHICLE_SPEED = 0x1803C0D0;
constexpr uint32_t CAN_ID_CLUSTER_BMS_STATUS = 0x18F3FFC0;
constexpr uint32_t CAN_ID_CLUSTER_BMS_DETAIL = 0x18F4FFC0;

// 디코더: raw_to_voltage(×0.1), raw_to_current(×0.1,-3200), raw_to_temp(-40), raw_to_speed(1rpm/bit,-32000)
// RX 파싱 구현: src/core/can_bus.cpp poll_rx() — 컨트롤러 피드백, VCU 표시 상태, VCU 단일 차량속도 프레임을 state에 반영
```

METER 경로(§5.5/5.6, 0.1rpm/bit)는 이 설계에서 사용하지 않는다 — 컨트롤러가 VCU 모드로 고정되므로 필요 없음.

---

## 9. 변경 관리

### Car Check 수신 계약 추가 (2026-09-09)

VCU Car Check v1 계약은 별도 미러 헤더 `include/car_check_protocol.h`에 정의한다. 기존 ID를 재할당하거나 VCU 정보를 Cluster에서 재송신하지 않는다. 기준 VCU 커밋: `8498e2f20cfa79f8c71416a25a2676677b59a270`.

| ID | 송신 → 수신 | 주기 | 주요 내용 |
| --- | --- | --- | --- |
| `0x1804C0D0` | VCU → Cluster/TMA-1 | 50 ms | Steering int16 LE ×0.001, Byte6 valid/metadata, Byte7 life |
| `0x1805C0D0` | VCU → Cluster/TMA-1 | 50 ms | Yaw deg/s, accel X/Y g, int16 LE ×0.01, Byte6 valid/metadata, Byte7 life |
| `0x1806C0D0` | VCU → Cluster/TMA-1 | 50 ms | FL/FR/RL/RR uint16 LE ×0.1 km/h, 0xFFFF invalid |
| `0x1807C0D0` | VCU → Cluster/TMA-1 | 50 ms | v1, 요청 수신값, 제어 상태와 차단 이유, life |

모두 Extended/DLC8. 300 ms 초과 시 stale. 구버전 Steering/IMU의 유효성 메타데이터가 없거나 Control 버전이 다르면 UNKNOWN으로 취급한다. 세부 비트 정의와 남은 요청은 `docs/ui_report/CAN_DATA_REQUIRED.md`를 참조한다.

- 이 파일과 `include/can_protocol.h`는 **글자 단위로 일치**해야 한다.
- 수정 시: ① 이 문서 갱신 → ② 양 레포의 `can_protocol.h` 동기화 → ③ 변경 요약을 팀 공지.
- 새 메시지 ID는 J1939 규칙(PF/PS/SA)에 맞게 할당하고 §4 표에 추가.

### 노드 리셋 원인 보고 `0x1CFDFF00 | SA` · 1s (2026-09-30)

VCU `0x1CFDFFD0`, Cluster `0x1CFDFFC0`, EM Gateway `0x1CFDFFC1`. Extended, DLC 8, Priority 7. 부팅 원인을 1초마다 반복 송신한다. 로거가 같은 순간 재부팅해도 다음 1초 안에 기록된다. monolith 로거는 CAN 대신 자기 SD에 시스템 이벤트 `RST:<원인>/<ROM 코드>`로 남긴다.

| 바이트 | 항목 | 비고 |
|---|---|---|
| 0 | `esp_reset_reason()` | 1 POWERON, 3 SW, 4 PANIC, 5 INT_WDT, 6 TASK_WDT, 7 WDT, 9 BROWNOUT |
| 1 | ROM 리셋 원인 (CPU0) | `esp_rom_get_reset_reason(0)`, 원인 세분(예: 15 RTCWDT_BROWN_OUT) |
| 2~5 | 부팅 후 경과 ms | uint32 LE |
| 6 | 전원 유지 중 리셋 횟수 | RTC no-init 메모리, POWERON이면 0, 255에서 포화 |
| 7 | life | 송신마다 +1 |

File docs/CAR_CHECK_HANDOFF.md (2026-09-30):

# Car Check redesign and team handoff

Updated: 2026-09-09. PM feedback is implemented locally after user approval. VCU Car Check v1 is integrated against the pinned commit below. Hardware validation is pending. No message has been sent to another team. Current Korean report and handoff: `docs/ui_report/REPORT.md`, `docs/ui_report/CAN_DATA_REQUIRED.md`.

## Accepted UI decisions

- Assume the touchscreen works normally.
- Main page -> Warning reasons (only when warnings exist) -> Car Check menu.
- Car Check has four touch targets: top-left Motor, top-right Power, bottom-left VCU/Sensors, bottom-right GPS/RTK.
- Each target opens decoded measurements with units and diagnostic states, not hexadecimal CAN payload dumps.
- Detail back navigation returns to Car Check.
- PCB V3 GPIO19 momentary button is HOME: pressing it from any page returns to the main page. Each non-home page also has a rectangular BACK touch target.
- Touching home WSS or throttle opens a continuously updated graph. Detail rows marked `*` also open graphs. Latest decision replaces the older 10-minute WSS buffer with 12 numeric channels at 2Hz for 60 seconds, fixed RAM, plus bounded RTK transitions and 32 boot-session events. There is no older-than-60-second scrollback in this version. Live display scheduling targets 20Hz.
- Display live zero as zero, missing values as --, and expired values as stale. Distinguish Cluster requests from VCU-confirmed applied states.
- Unspecified signals must not be invented or shown as measured zero. Integrate them after the user supplies the VCU team's confirmed CAN specification.

## VCU / torque-vectoring team handoff

The earlier new-sender backlog is superseded by the pinned VCU review below. Current Cluster receives all four Car Check frames. Confirm vehicle deployment and interpretation; request a new sender only for missing measurements such as calibrated brake pressure.

| Item | Request / confirmation needed |
| --- | --- |
| Four individual wheel speeds | 0x1806C0D0 is integrated, FL/FR/RL/RR, unsigned LE x0.1, 0xFFFF invalid. Confirm wheel calibration and physical sensor validity criteria. |
| Steering | 0x1804C0D0 is integrated, normalized x0.001, not degrees. Confirm deployed validity metadata and steering direction. |
| IMU | 0x1805C0D0 is integrated, yaw deg/s and accel X/Y g, x0.01. Confirm sensor mounting/vehicle-axis sign. |
| TV applied state | GPIO32 request remains 0x1801D0C0 Byte1 bit0. 0x1807C0D0 v1 echoes requests and reports active/block status. Verify deployed VCU version. |
| Regen applied state | Rotary 0=OFF, 1/2/3=the same ON; 0x1801D0C0 Byte1 bit1 is boolean enable. 0x1807C0D0 v1 reports permission/active/block status, not measured charging power. |
| Signal contract | For each signal supply ID, Extended/Standard, DLC, byte/bit positions, signedness, endian, scale/offset, unit, period, validity/sentinel, counter and timeout guidance. Intended consumers include both Cluster and TMA-1. |

Already received by Cluster: gear, brake, HV active, throttle with valid flag, Paddock applied feedback via 0x1801C0D0, and representative WSS speed via 0x1803C0D0. Do not request these as entirely new functions.

Controller bus/phase current, RPM, temperatures and faults originate in direct controller feedback. Add missing Cluster parsing/display instead of asking VCU to retransmit them. BMS and EM data also have independent sources.

Implemented: controller phase current, EM HV current/CPU temperature, four wheels, steering, IMU and TV/regen diagnostics. Brake pressure remains NOT PROVIDED. Missing/stale/invalid/legacy metadata are distinguished. HV SOC remains BMS-sourced; LV has voltage only. Current magnitude uses abs(EM V*I); charge/discharge direction remains unconfirmed.

## Wiring / PCB team handoff

| Function | GPIO / connection | Note |
| --- | --- | --- |
| TV ON/OFF switch | GPIO32 to GND | PCB 10k external pull-up, active-low. |
| Regen rotary bit0 | GPIO36 | External pull-up, active-low. |
| Regen rotary bit1 | GPIO39 | External pull-up, active-low. |
| Rotary common | GND | 0=OFF; 1/2/3 identical ON, not three strengths. |
| HOME momentary button | GPIO19 to GND | PCB 10k external pull-up, active-low. |
| GPS LAP momentary button | GPIO5 to GND | PCB 10k external pull-up, active-low. |
| VESS PWM output | GPIO4 | 50Hz PWM before the inverting MOSFET; RX-TH receives a 1-2ms HIGH pulse. |
| Paddock | GPIO33 | PCB 10k external pull-up, active-low. |
| START_IN sense | GPIO34 | ADC presence input; shown on VCU/SENSOR detail page. |

The UI redesign itself needs no extra analog wiring. EM voltage data arrives over the existing 250kbps CAN bus.

## Follow-up evidence: 2026-09-09

Read-only GitHub review of VCU dev commit `8498e2f20cfa79f8c71416a25a2676677b59a270`
(2026-09-08, combined test-week changes). No firmware or decoder JSON was changed in this review.

- Brake pressure telemetry is still absent. PCB V3 assigns VCU GPIO39 to pressure
  and GPIO35 to divided brake ON/OFF, but current VCU control reads only GPIO35 when
  `BRAKE_SENSOR_INSTALLED` is true. That flag is currently false. `brake_compute()`
  maps its input to 0/100 percent; this is not a calibrated pressure measurement.
  Ask VCU for installed sensor identification, ADC acquisition, calibrated bar/MPa,
  invalid/fault handling and a published CAN contract, not merely a pressure decoder.
- IMPORTANT update to the earlier backlog: VCU now sends steering 0x1804C0D0,
  IMU 0x1805C0D0, four wheels 0x1806C0D0 and control diagnostics 0x1807C0D0.
  `send_sensor_telemetry()` is called by the 50ms scheduler task. See
  https://github.com/2026-HEVEN/vcu/blob/8498e2f20cfa79f8c71416a25a2676677b59a270/docs/CAR_CHECK_CAN.md
  These signals no longer require a request for a brand-new VCU sender. Local UI
  integration / existing remote Cluster changes must be reconciled separately.
- Steering numeric scaling remains signed int16 /1000 normalized (not degrees).
  IMU remains signed int16 /100, yaw deg/s and acceleration g in sensor axes.
  Byte6 validity bits and byte7 life are now part of both frames. Wheels use
  uint16 LE x0.1 km/h, FL/FR/RL/RR, with 0xFFFF invalid. Control byte0 is version 1;
  byte1 is echoed requests, byte2 observed states, bytes3/4 block reasons, byte7 life.
  Regen active is a command/pipeline observation, not measured recovered power.
- Supplied `107signals (1).json` has exactly 107 CAN decoders. Missing: EM RECORD
  0x1CF5FFC1 and SYNC 0x1CF6FFC1, four wheels/control diagnostics, steering/IMU validity
  and life, throttle/valid and applied Paddock in 0x1801C0D0, BMS valid/BLE/life and
  BMS detail 0x18F4FFC0. It contains Brake Active, not brake pressure. Existing
  TV/regen/Paddock entries on 0x1801D0C0 describe requests, not applied feedback.
  The Debug entry is legacy/reserved, not VESS PWM. Decoder existence is not proof
  of actual reception. Invalid wheel 0xFFFF must not display as 6553.5 km/h.
- HV SOC comes from BMS BLE (`bms_ble.cpp::apply_summary`), not EM. EM has HV V/I,
  LV supply V, CPU temperature, and separate sync/status; neither HV nor LV SOC is
  supplied by the cited EM contract. A voltage bar must not be labelled SOC.

### Include in the next report: interpretation and vehicle-test checklist

- PM PDF `BMS·motor-controller current based 10 kW limit` (2026-09-08), pp1-2/6:
  intended EM installation is the common HV path before the L/R controller split.
  Treat actual installation as a vehicle check, not proven by the document.
- Determine EM current polarity with known discharge/charge operation. Keep signed
  V*I for CHARGE/POWER display; the PDF's abs(V*I) limiter sketch loses direction.
- Confirm LV chemistry, voltage range and actual EM supply measurement point.
  LV SOC still requires an appropriate independent SOC source/estimator.
- Confirm steering left/right sign and IMU mounting axes; contract units are now
  known but vehicle-axis calibration is not. Verify wheel scaling and sensor validity.
- Determine power-bar full-scale separately for discharge/charge. PM's 10kW
  control target is not automatically the charge full-scale or proof of compliance.
- Measure actual EM CAN cadence/reception. Producer parser tests and successful
  firmware builds do not prove installed vehicle operation at 100Hz.
- PDF reports approximately 139ms median BMS CAN arrival on the analyzed run and
  slow value changes. Separate that observation from nominal 100ms Cluster scheduling.

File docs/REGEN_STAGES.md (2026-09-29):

# 회생 로터리 단계 송신 (2026-09-29)

Cluster는 기존 GPIO 로터리의 2비트 입력을 항상 0/1/2/3으로 송신한다.
ON/OFF 또는 4단계 해석과 원페달/브레이크 작동 조건은 VCU의
`src/modules/realcar_calibration.h`에서만 설정한다.

`0x1801D0C0` Extended, DLC 8:
- Byte1 bit1: 단계가 1..3이면 ON, 0이면 OFF (기존 호환).
- Byte3: 단계 0/1/2/3 → 0xA0/0xA1/0xA2/0xA3.
- 잘못된 로터리 값(3 초과)은 OFF로 송신.
- 나머지 TV/Debug/Paddock 비트·송신 주기는 유지.

구형 VCU는 Byte3를 무시하므로 1/2/3 모두 같은 세기로 작동한다.
단계 시험에는 VCU도 함께 업데이트해야 한다. 계기 ON/OFF 표시를
실제 VCU 적용 단계의 확인으로 사용하지 말 것.

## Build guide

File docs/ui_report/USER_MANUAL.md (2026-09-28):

# HEVEN Cluster 계기판 사용설명서

기준일: 2026-09-28. 대상: PCB V3 Cluster ESP32 / 320×240 ILI9341 LCD.

이 설명서는 운전자가 계기판에서 무엇을 확인하고 어떤 부분을 눌러야 하는지 정리한 문서다. 화면의 `--`, `WAIT`, `STALE`, `INVALID`는 실제 값 0이 아니라 데이터가 없거나 유효하지 않다는 뜻이다.

## 1. 기본 화면 읽기

기본 화면

| 위치 | 표시 | 의미 |
| --- | --- | --- |
| 왼쪽 큰 숫자 | WSS 기반 속도 | VCU가 보낸 대표 차량속도, km/h |
| 오른쪽 위 | N / R / D | 현재 기어. 차량에는 P가 없음 |
| 기어 왼쪽 | BRK | 유효한 VCU Brake Active가 ON일 때만 표시 |
| 오른쪽 막대 | HV SOC | BMS BLE에서 받은 고전압 배터리 잔량 |
| 오른쪽 아래 | HV / LV 전압 | 임시 EM Gateway가 보낸 현재 전압 |
| THR | 스로틀 % | VCU가 보낸 유효한 스로틀 전개율 |
| CHR–0–PWR | 전력 | 왼쪽은 충전, 오른쪽은 소비. 숫자는 전력 절댓값 kW |
| L 번호와 시간 | 현재 랩 | 현재 진행 중인 랩 번호와 경과시간 |
| BEST | 최고 랩 | 완료된 랩 중 가장 빠른 기록 |

`BRK`는 압력이나 제동력을 의미하지 않는다. 브레이크 ON/OFF 신호가 켜졌다는 뜻이며 VCU 상태 프레임이 300 ms 이상 오래되면 표시를 지운다.

## 2. 기본 화면에서 터치하기

### 속도 그래프

큰 속도 숫자를 누르면 최근 60초 WSS 그래프가 열린다.

WSS 속도 그래프

### 전력 그래프

중앙의 CHR–0–PWR 막대를 누르면 최근 60초 전력 그래프가 열린다. 세로축은 전력 절댓값이며 POWER 구간은 실선, CHARGE 구간은 점선이다.

전력 그래프

### Car Check 또는 Warning

속도 숫자와 전력 막대를 제외한 기본 화면을 누른다.

- Warning이 없으면 Car Check 메뉴로 이동한다.
- Warning이 있으면 Warning 원인 화면으로 이동한다.
- 세부 화면 오른쪽 위 `BACK`을 누르면 이전 화면으로 돌아간다.
- PCB V3의 GPIO19 순간버튼을 누르면 어느 화면에서나 기본 화면으로 돌아간다. LCD 터치가 불편할 때 사용하는 HOME 버튼이다.

## 3. Car Check 사용법

Car Check 메뉴

네 영역 중 확인할 항목을 누른다.

| 메뉴 | 확인 가능한 정보 |
| --- | --- |
| MOTOR | 좌/우 버스 전압·버스 전류·상 전류·RPM·온도·상태·고장 |
| POWER | BMS SOC·전압·전류·온도와 EM HV/LV 전압·HV 전류·CPU 온도 |
| VCU/SENSOR | 기어·브레이크 ON/OFF·HV·스로틀·WSS·조향·IMU·4륜 속도·제어 상태·START 입력 |
| GPS/RTK | Fix·RTK·위경도·위성·HDOP·Wi-Fi·NTRIP·RTCM·PPS·랩 상태 |

세부 화면에서 항목 왼쪽에 `*`가 있으면 해당 행을 눌러 최근 60초 그래프를 볼 수 있다.

모터 상세

전원 상세

VCU 및 센서

GPS 및 RTK

## 4. 연결 상태와 과거 이력

세부 화면 아래의 `LINKS / HISTORY`를 누르면 연결 상태를 확인할 수 있다.

연결 상태

- `LIVE`: 현재 연결됨
- `WAIT`: 부팅 후 아직 유효 프레임을 받지 못함
- `LOST`: 전에 연결됐으나 현재 끊김
- 시간: 현재 연결이 연속 유지된 시간
- `D`: 연결이 끊긴 횟수
- `F`: 새로 발생한 모터 고장 bit 누적 횟수

`EVENTS`에서는 최초 연결, 단절, 복구, 모터 고장 발생과 해제를 최근 32건까지 확인한다.

발생 이력

이 이력은 RAM에만 저장되므로 계기판 전원을 끄면 사라진다. 장시간 기록과 사후 분석에는 TMA-1 로그를 사용한다.

## 5. Warning 화면

모터컨트롤러 고장 bit가 발생하면 즉시 붉은 Warning 상태가 된다. 좌·우 모터컨트롤러 피드백 또는 VCU 상태 CAN이 끊기면 순간적인 지연은 무시하고 1초 이상 지속될 때 Warning 상태가 된다. 전원 투입 후 처음 3초는 CAN 시작 유예시간이다.

기존 좌우 모터 RPM으로 다음 구동계 이상 징후도 감시한다.

- `DRIVE RPM WARNING`: 회전 중 한쪽 RPM이 0 부근으로 반복 결손됨
- `DRIVE SYSTEM FAULT`: 좌우 RPM이 큰 비율로 200 ms 이상 발산함
- `LEFT MOTOR` / `RIGHT MOTOR`: 이상이 의심되는 쪽

이 경고는 CAN 패턴에 따른 **구동계 또는 RPM 피드백 이상 경고**이며 특정 부품 파손을 확정하지 않는다. 경고는 운전자가 알아볼 수 있도록 5초간 우선 표시되고, 발생 이력은 재부팅 전까지 유지된다. CAN 수신 중단은 RPM 이상과 별도로 처리한다.

Warning 화면

Warning 화면에서 원인을 확인할 수 있다. Warning 중에도 GPS LAP 버튼은 사용할 수 있다. 원인이 사라지면 Warning 화면에서 Car Check 메뉴로 전환된다.

## 6. GPS LAP 버튼

GPS LAP 버튼은 PCB V3 GPIO5에 연결된 순간버튼이다.

| 조작 | 결과 |
| --- | --- |
| 처음 한 번 누름 | 현재 유효 GPS 위치를 Start/Finish 중심점으로 저장하고 `LAP START SET` 표시 |
| 진행 중 한 번 누름 | 현재 랩타이머만 정지하고 `LAP STOPPED` 표시. 기준점과 기록은 유지 |
| 정지 후 한 번 누름 | 기존 랩을 이어서 재개하고 `LAP RESUMED` 표시. 멈춘 시간은 제외 |
| 320 ms 이내 빠른 두 번 누름 | 기준점·가상 결승선·랩 기록을 모두 지우고 `GPS LAP RESET` 표시 |

단일 클릭은 더블클릭 여부를 판별하므로 약 320 ms 뒤 실행된다. GPS 데이터가 없으면 `NO GPS DATA`, 데이터는 있지만 Fix가 없으면 `NO GPS FIX`가 표시된다.

Start/Finish 중심점에서 차량이 출발하면 최근 GPS 이동 방향을 이용해 진행 방향을 구하고, 그 방향에 수직인 좌우 5 m의 가상 결승선을 만든다. 이동 선분이 같은 진행 방향으로 결승선을 통과하면 랩을 완료한다. 시작 직후 화면은 `L1`이며 첫 결승선 통과 후 `L2`로 넘어간다.

## 7. 차량 설정 스위치

| 입력 | 현재 기능 |
| --- | --- |
| Paddock | VCU에 Paddock 제한모드 요청 전송 |
| TC | 토크벡터링 ON/OFF 요청 전송 |
| Regen 로터리 | 0=OFF, 1·2·3=동일 ON 요청 |
| GPIO19 순간버튼 | 계기판 기본 화면으로 복귀 |
| GPS LAP 순간버튼 | 랩 시작·정지·재개·초기화 |
| GPIO4 | VESS PWM 출력. 버튼 입력이 아님 |
| GPIO34 START_IN | 30 kΩ/10 kΩ 분압을 거친 START 상태 감시. 차량 제어에는 사용하지 않음 |

스위치의 요청 상태와 VCU가 실제로 적용한 상태는 다를 수 있다. Car Check의 CONTROL 화면에서 요청 수신, 실제 Active, 차단 이유를 함께 확인한다.

## 8. 표시가 이상할 때

| 표시 | 확인할 내용 |
| --- | --- |
| `-- WAIT` | 해당 CAN/BLE/GPS 프레임을 아직 받지 못했거나 timeout 발생 |
| `STALE` | 예전 값은 있으나 최신 수신 시간이 허용 범위를 넘음 |
| `INVALID` | 송신 ECU가 값이 유효하지 않다고 표시함 |
| `UNKNOWN` | 구버전 프레임 등으로 유효성 정의를 확인할 수 없음 |
| `BRK`가 안 뜸 | 브레이크가 OFF이거나 VCU 상태 프레임이 오래됨 |
| LV %가 없음 | 현재 LV SOC 데이터가 없으며 전압만 수신 가능 |
| 그래프의 선이 끊김 | 그 시간 구간의 데이터가 유효하지 않거나 연결이 끊김 |

화면은 20 Hz 갱신을 목표로 하지만 새로운 측정값의 속도는 각 CAN·BLE·GNSS 원천 주기에 의해 결정된다. 그래프는 2 Hz, 최근 60초 추세 확인용이며 정밀 분석용 원본 로그가 아니다.

## 9. 현재 사용상 주의

- HV/LV와 전력은 임시 EM Gateway 데이터에 의존하며 대회 공식 에너지 판정값이 아니다.
- 충전/방전 방향은 실차에서 전류 부호를 확인해야 한다.
- LV SOC와 브레이크 압력은 현재 표시할 수 없다.
- Steering은 정규화 값이며 실제 조향각으로 확정되지 않았다.
- IMU 축과 부호, 개별 WSS 보정은 차량 장착 상태에서 검증해야 한다.
- 연결/고장 이력은 전원을 끄면 초기화된다.
- START 화면 전압은 GPIO34에서 측정한 분압 후 ADC 전압이며, 원래 9~12 V 입력 전압이 아니다.
- 구동계 이상 감지는 초기 임계값 기반의 운전자 경고 기능이다. 실제 토크 제한이나 차단은 수행하지 않는다.

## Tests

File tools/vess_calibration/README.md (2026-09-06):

# VESS Calibration Sketch

Standalone ESP32 code for checking the VESS signal on GPIO26 without changing
the Cluster firmware.

## Wiring

```text
ESP32 GPIO26 -> VESS signal input
ESP32 GND    -> VESS GND/common ground
```

Power the VESS module according to its own power requirements. Do not power it
from a weak ESP32 rail if the module needs more current.

## Current Cluster PWM Reference

The current Cluster firmware drives VESS with 50 Hz servo-style PWM:

| Logical throttle | Meaning | Pulse width | Team sound level label |
| --- | --- | --- | --- |
| -1.0 | Reverse throttle | 1000 us | 15 |
| 0.0 | Idle / neutral | 1500 us | 20 |
| +1.0 | Full forward throttle | 2000 us | 30 |

The reverse pulse is provisional for calibration because the production reverse
calibration value has not been confirmed yet.

## Upload

From this folder:

```powershell
$env:PLATFORMIO_CORE_DIR='C:\heven\cluster\.pio-core'
& 'C:\Users\김민철\AppData\Roaming\Python\Python311\Scripts\platformio.exe' run -t upload --upload-port COM4
```

## Serial Commands

Open the serial monitor at 115200 baud.

```text
i     idle, throttle 0.0
f     full forward, throttle +1.0
r     reverse, throttle -1.0
0..9  forward throttle 0.0..0.9
+     increase throttle by 0.05
-     decrease throttle by 0.05
s     slow sweep -1.0 -> 0.0 -> +1.0 -> 0.0
p     print current status
h/?   help
```

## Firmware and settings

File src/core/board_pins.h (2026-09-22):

#pragma once

// Physical Cluster PCB V3 pin map.
// Source of truth: Notion "PCB V3 설계" (2026-09-17).
namespace board_pins {
constexpr int LCD_CS = 23;
constexpr int LCD_RST = 22;
constexpr int LCD_DC = 21;
constexpr int SPI_MOSI = 17;
constexpr int SPI_SCK = 18;
constexpr int SPI_MISO = 35;
constexpr int TOUCH_CS = 16;

constexpr int CAN_RX = 14;
constexpr int CAN_TX = 13;

constexpr int GNSS_RX = 25;
constexpr int GNSS_TX = 26;
constexpr int GNSS_PPS = 27;

constexpr int VESS_PWM = 4;
constexpr int TV_SWITCH = 32;
constexpr int PADDOCK_SWITCH = 33;
constexpr int HOME_BUTTON = 19;
constexpr int LAP_BUTTON = 5;
constexpr int REGEN_BIT0 = 36;
constexpr int REGEN_BIT1 = 39;
constexpr int START_SENSE_ADC = 34;
} // namespace board_pins

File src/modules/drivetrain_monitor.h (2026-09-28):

#pragma once

#include <cstdint>

enum class DrivetrainSide : uint8_t { Left = 0, Right = 1 };
enum class DrivetrainFault : uint8_t { None = 0, RpmDropout = 1, RpmDivergence = 2 };

struct DrivetrainMonitorConfig {
    int moving_rpm = 200;
    int divergence_rpm = 800;
    uint8_t divergence_ratio = 3;
    uint8_t dropout_limit = 3;
    uint32_t dropout_window_ms = 2000;
    uint32_t dropout_recovery_ms = 150;
    uint32_t pair_fresh_ms = 100;
    uint32_t divergence_hold_ms = 200;
};

struct DrivetrainMonitorEvent {
    bool triggered = false;
    DrivetrainSide side = DrivetrainSide::Left;
    DrivetrainFault fault = DrivetrainFault::None;
    uint32_t ms = 0;
};

struct DrivetrainMonitorStatus {
    DrivetrainFault left = DrivetrainFault::None;
    DrivetrainFault right = DrivetrainFault::None;
    uint16_t left_dropouts = 0;
    uint16_t right_dropouts = 0;
    uint32_t left_last_event_ms = 0;
    uint32_t right_last_event_ms = 0;
};

class DrivetrainMonitor {
public:
    explicit DrivetrainMonitor(const DrivetrainMonitorConfig &config = {});
    DrivetrainMonitorEvent receive(DrivetrainSide side, int rpm, uint32_t now);
    const DrivetrainMonitorStatus &status() const { return status_; }
    void reset();

private:
    struct SideState {
        int rpm = 0;
        uint32_t rx_ms = 0;
        bool seen = false;
        bool zero_pending = false;
        uint32_t zero_started_ms = 0;
        static constexpr uint8_t MAX_DROPOUT_LIMIT = 8;
        uint32_t dropout_times[MAX_DROPOUT_LIMIT]{};
        uint8_t dropout_head = 0;
        uint8_t dropout_count = 0;
    };

    DrivetrainMonitorConfig config_;
    SideState sides_[2]{};
    DrivetrainMonitorStatus status_{};
    bool divergence_pending_ = false;
    bool divergence_reported_ = false;
    DrivetrainSide divergence_side_ = DrivetrainSide::Left;
    uint32_t divergence_started_ms_ = 0;

    DrivetrainMonitorEvent confirm_dropout(DrivetrainSide side, uint32_t now);
    DrivetrainMonitorEvent evaluate_divergence(uint32_t now);
};

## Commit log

2026-07-26 ci: esp32dev 빌드 잡 추가 (#6)
    기존 CI는 `pio test -e native`만 돌렸는데, native env는
    build_src_filter로 modules/ + logic/ 만 컴파일한다. 그 결과
    main.cpp 와 core/ 전체(can_bus, display_blit, bms_ble,
    gps_laptimer, scheduler)가 CI에서 컴파일된 적이 없다.
    vcu 레포에서는 같은 잡을 추가하자마자 main 브랜치가 플래시
    불가능한 상태였던 것이 드러났다(Arduino.h 매크로 충돌).
    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
2026-08-05 feat(cluster): add wheel speed display integration (#8)
    * feat(cluster): add wheel speed display integration
    * feat(cluster): toggle car check with lcd touch
    * feat(cluster): start lap timer from wheel speed
    * feat(cluster): show lv voltage on car check
    * ci: run KiCad DRC on 김민철2 branch
    * hardware: add cluster RevB PCB layout
    * fix(hardware): reroute Cluster RevB R2
    * fix(hardware): reroute Cluster RevB R3
    * fix(hardware): connect RevB ground zones R4
    * fix(hardware): resolve RevB footprint library warnings R5
    * feat(cluster): remap ESP32 GPIO for revised PCB wiring
    * feat(cluster): consume VCU single vehicle speed
    * docs(cluster): update native test count
    * fix(cluster):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
    [HEVEN_Cluster_RevA.kicad_pcb]
2026-08-30 ci: dev 브랜치 push에도 CI 실행
    dev는 승인 없이 직접 push가 가능하므로, 빌드/테스트 깨짐이 즉시
    보이도록 push 트리거에 dev를 추가한다. 강제 게이트는 아니며
    main 병합 시점의 required check는 그대로다.
2026-09-01 refactor(cluster): remove water pump command
2026-09-05 feat(cluster): drive VESS from VCU throttle
2026-09-10 fix(lap): show current lap using race numbering
    [check_snapshot.cpp, gps_laptimer.cpp]
2026-09-22 fix: align Cluster pin map with PCB V3
    [board_pins.h, gps_laptimer.cpp, test_board_pins.cpp]
2026-09-28 feat(cluster): support PCB V3 and drivetrain warnings
2026-09-28 docs(cluster): update PCB V3 manual and warning report
2026-09-28 fix(cluster): 차속 invalid 순간에 '--' 대신 직전 값을 표시
    09-27 주행에서 VCU 차속 프레임의 9~26%가 invalid(가속 중 WSS 판정
    흔들림)로 와서 홈 화면 속도가 수시로 '--'로 바뀌었다. CAN 두절은
    아니었다(300ms 넘는 공백 1회).
    - decode_vcu_vehicle_speed: 플래그와 무관하게 값을 해독한다.
    - can_bus: invalid 프레임은 직전 valid 값을 유지한다. 구버전 VCU는 invalid일
    때 0을 보내므로 그대로 쓰면 0으로 튄다. valid 수신 시각을 기록한다.
    - 홈 화면: 프레임이 300ms 안에 왔고 valid가 1초 안에 한 번이라도 있었으면
    숫자를 표시. 프레임 두절이나 1초 넘는 i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
    [check_snapshot.cpp, test_diagnostics.cpp]
2026-09-28 fix(cluster): 터치 디바운스 재작성 + 4점 캘리브레이션(NVS 저장)
    - 떼기 60ms/2샘플 확인, 누르기 2샘플 확인 → 압력 흔들림으로 한 번 누름에 여러 탭이 나가던 문제 수정
    - 탭 좌표를 첫 접촉 샘플 대신 누름 구간 중앙값으로, 탭 후 250ms 락아웃
    - 터치 폴링을 HMI(50Hz)에서 분리해 100Hz 태스크로
    - HOME 3초 길게 누르기 또는 시리얼 'cal'로 4코너+중앙 검증 캘리브레이션, NVS 저장
    - 시리얼 'touch'로 raw 로그 + 화면 커서 표시, 'caldef'/'calshow'
    [touch_input.h]
2026-09-28 perf(cluster): 터치를 누르는 순간 처리 + 화면은 바뀐 행만 전송
    - 탭을 떼기 후가 아니라 누름 확인(2샘플) 즉시 발생, 떼기 디바운스는 중복 방지용으로만
    - display_blit: 이전 프레임과 다른 행만 전송 (전체 60ms → 평상시 0.7ms)
    기존에는 display 태스크(50ms 주기)가 CPU를 거의 점유해 터치가 약 60ms마다만 읽혔음
    - 전체 화면 갱신 중에도 24행마다 터치 폴링(idle hook)
    - touch 디버그 모드에서 blit 시간 로그
2026-09-29 feat(can): always transmit four-stage regen request to VCU
2026-09-29 feat(gnss): broadcast RMC ground speed
2026-09-30 feat(can): reset-cause report 0x1CFDFFC0, drive CAN TXD from first boot
    The 09-30 drive logs show the cluster rebooting four times at ~180 A,
    each followed by a 1.35-1.8 s bus-wide block that forced both motor
    controllers to re-handshake. Nothing recorded why it rebooted.
    - Report the cause of the current boot every second (layout shared by
    every ESP32 node: b0 esp_reset_reason, b1 ROM reason, b2-5 uptime ms,
    b6 resets since power-on, b7 life).
    - Hold GPIO13 (CAN TXD) HIGH at the top of setup() and start TWAI before
    the LCD init and first full frame, so the transceiver input is never
    left to the reset default while the cluster boots. The ROM boot window
    before setup() is still unc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
    [main.cpp]
2026-09-30 fix(ntrip): run Wi-Fi/NTRIP in its own task
    With the hotspot absent, the cluster went silent on CAN for 0.4-1.4 s
    every 5 s while parked (09-30 logs): WiFi.begin() and the 1 s caster
    connect() ran inside the cooperative scheduler, stalling display, CAN RX
    and TX together.
    - ntrip::start_task() runs the Wi-Fi/NTRIP state machine on core 0 at
    priority 1 (5 s start delay kept). Other tasks read cached values only
    (wifi_connected / connected / status_label / RTCM counters).
    - gps_laptimer: a mutex serialises RTCM writes against the NMEA-timeout
    UART re-open, and copy_last_gga() replaces last_gga_sentence() so the
    NTRIP task never reads a GGA line mid-write.
    Locked core files edited wit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
    [gps_laptimer.cpp, ntrip.cpp]
2026-09-30 fix(ntrip): signed age for stamps written by the other core
    After moving NTRIP to its own task, GGA stamps from the GPS parser (core 1)
    could be a few ms newer than the NTRIP task's `now`, so `now - stamp`
    wrapped and a 0.2 s old GGA was reported stale ("No fresh GGA", "GGA
    stale" on the bench). The same applies the other way for last_rtcm_ms()
    read by the CAN encoder and Car Check. Treat a future stamp as age 0.
    [check_snapshot.cpp, ntrip.cpp]
2026-09-30 fix(bms): run BLE scan/connect in its own task
    Bench 2026-09-30 (pull-up log): with the BMS link down the cluster went
    silent on CAN for 1.1 s every 15 s. bms_ble::poll() ran in the scheduler
    and its retry path blocks: a 1 s NimBLE scan, then connect() and a 160 ms
    handshake when the BMS is found.
    - bms_ble::start_task() runs scan/connect/summary polling on core 0 at
    priority 1 (10 Hz as before). Notify callbacks already land on the
    NimBLE host task, so `state` sees no new writer.
    - bms_last_rx_ms is written by that callback and may be newer than the
    reader's `now`: compare with a signed age in bms_ble and in the BMS CAN
    frame freshness, as already done for NTRIP stamps.
    Locked cor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
2026-09-30 fix: invert Cluster VESS PWM for external signal stage (#19)
    vess 수정
2026-09-30 fix(can): recover from bus-off by reinstalling the TWAI driver
    The Cluster had no bus-off handling: once TEC passed 255 it stayed silent
    until power-cycled, and the VCU then drops the regen request and every
    other Cluster command. The 2026-10-01 03:08 drive already showed the
    Cluster's own frames stalling for 213-330 ms during high-speed regen
    (phase current 700-900 A) while VCU and energy-meter frames were intact.
    Same approach as the VCU (vcu 0c27448), not twai_initiate_recovery(),
    which in ESP-IDF 4.4.x can trip assert(tx_msg_count >= 0) in twai.c:
    - poll_rx() checks the TWAI state; on bus-off it sets g_twai_offline so
    every transmit returns at once and reception is skipped,
    - after 20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
2026-09-30 fix(cluster): send the VCU command from its own task + loop timing
    The VCU marks the Cluster command 0x1801D0C0 stale after 200 ms and then
    drops the regen request and TV. Every 2026-10-01 drive log shows 55-82
    command gaps > 200 ms per minute (max 850 ms, 90th percentile 123 ms, 23-28 Hz
    instead of 50 Hz), with no CAN errors in the 03:27 log, so regen chattered
    between 0 and -500 A. The command was sent from the shared cooperative loop,
    behind rendering, the LCD blit, serial and GPS work.
    - Switch reading, hmi_compute() and send_command() now run in a FreeRTOS
    task on core 1 (priority 3, above loop() at 1) every 20 ms. It never
    touches the SPI bus shared by the LCD and the touch contro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
2026-09-30 fix(gps): give the GPS UART a TX ring buffer so RTCM writes stop stalling the loop
    Loop timing (eb8d0fb) on the bench showed gps_update() taking 270-460 ms
    while NTRIP was streaming RTCM, not the LCD blit. The Arduino UART mutex
    is held for the whole of a write, and with no TX ring buffer (the default)
    a 256-byte RTCM chunk from the NTRIP task blocks until it drains through
    the 128-byte FIFO at 115200 baud. poll() took that mutex twice per byte
    (available() + read()), so it waited out every RTCM burst.
    - setTxBufferSize(4096) before the first begin(); kept across end()/begin()
    - poll() reads in 128-byte chunks: one mutex take per chunk
    Bench, RTK FIXED with NTRIP streaming, three 30 s wind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
    [gps_laptimer.cpp]
2026-10-02 Revert "feat: show neutral check beside start input diagnostics"
    This reverts commit 8b9ce9d993606f72322f3c25c393dbdbdd8fb015.
    [check_snapshot.cpp]
2026-10-02 fix(ntrip): tolerate brief RTCM gaps
    [ntrip.cpp]
2026-10-03 feat(cluster): publish per-lap telemetry and BMS diagnostics
    Replace energy-meter display data with BMS HV diagnostics. Add stable per-lap time and battery telemetry with distributed completed-lap refresh. Keep active lap 5 Hz updates and reset behavior. Stabilize NTRIP reconnect handling while retaining Wi-Fi sleep. User explicitly approved core/protocol changes. Native tests: 147 passed.
    [check_snapshot.cpp, diagnostic_history.cpp]
2026-10-03 feat: receive and display VCU LV supply voltage
2026-10-03 feat(cluster): add lap temperature telemetry and home LV voltage
    Approved core/protocol updates integrate time-weighted lap controller temperature statistics and nonblocking telemetry retries. Add home LV freshness display and validated Monolith configurations wit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
2026-10-03 perf(telemetry): slow older lap replay outside recent ten slots
    Keep active lap at 5 Hz, recent nine completed laps at 1 Hz each, and older laps at 0.1 Hz. Preserve final announcements and reset semantics. Add Monolith configs without standalone validity decoders. Protocol tests: 42 passed; ESP32 build passed.
